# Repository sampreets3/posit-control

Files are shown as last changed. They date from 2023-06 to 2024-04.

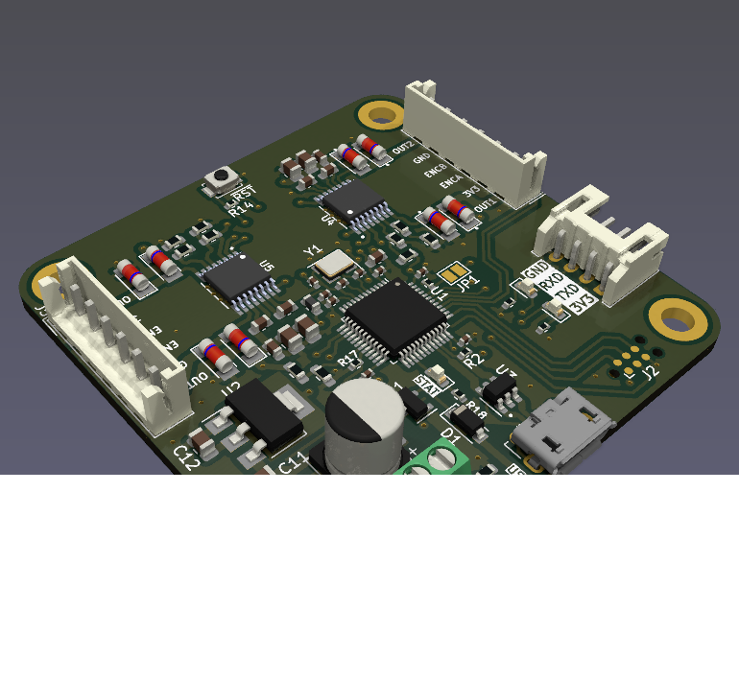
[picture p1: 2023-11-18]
images/four-layer-board.png

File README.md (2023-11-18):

# posit-control

Posit is an STM32-based DC motor controller designed to provide an efficient and reliable solution for controlling DC motors in various applications. This README file provides an overview of the Posit motor controller, its features, and instructions on getting started and using it in your projects.

---

## Features

- __STM32F1 Microcontroller:__ Posit is built around the STM32F103 microcontroller, known for its reliability and high-performance capabilities.

__USB Control:__ Posit acts as a USB Virtual COM Port, for sending over commands via usb->serial interfaces.

__UART Communication:__ UART interface for communication with external devices or microcontrollers.

---

## Usage

The Posit STM32 DC Motor Controller is highly customizable to fit a wide range of applications. You can control the motor speed and direction using PWM signals, monitor current feedback, and interface with external sensors for more advanced control.

Here is a basic example of controlling a motor using Posit:

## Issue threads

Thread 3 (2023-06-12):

Create Base Schematic

sampreets3, 2023-06-12:
Base Schematic Capture by defining requirements:

- [x] DRV8874
- [x] Microcontroller to interface with the driver
- [x] Power circuitry
- [x] USB data communication
- [ ] Optional: SPI LED bar control

sampreets3, 2023-06-25:
Added in commit cffd102.

Closed 2023-10-05.

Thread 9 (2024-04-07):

Add a debug LED on the board

aniketSaha1997, 2024-04-07:
Currently there are status LEDs but an additional LED would be good to have which can be helpful during debugging. For example - In case of the motor PWM apis, the LED could have been an added benefit in order to test whether the PWMs are set properly or not.

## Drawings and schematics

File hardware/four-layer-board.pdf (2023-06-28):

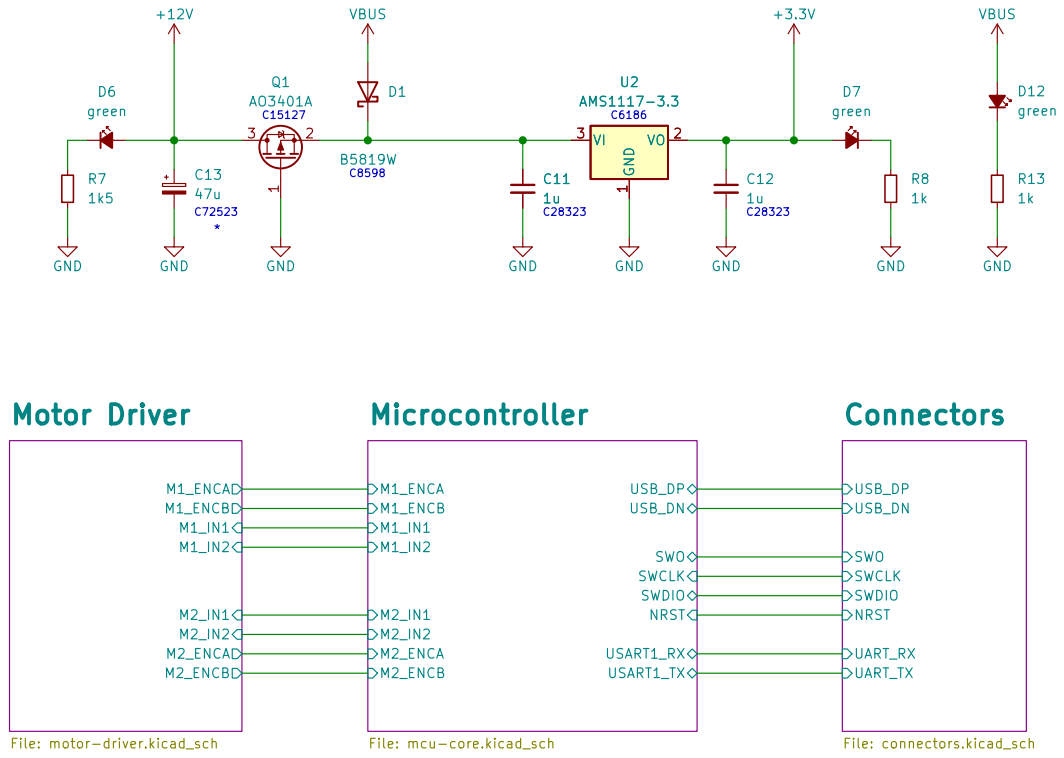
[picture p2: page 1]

Id: 1/4 Title: Posit: A STM32 based DC motor controller File: four-layer-board.kicad_sch Sheet: / Sampreet SARKAR

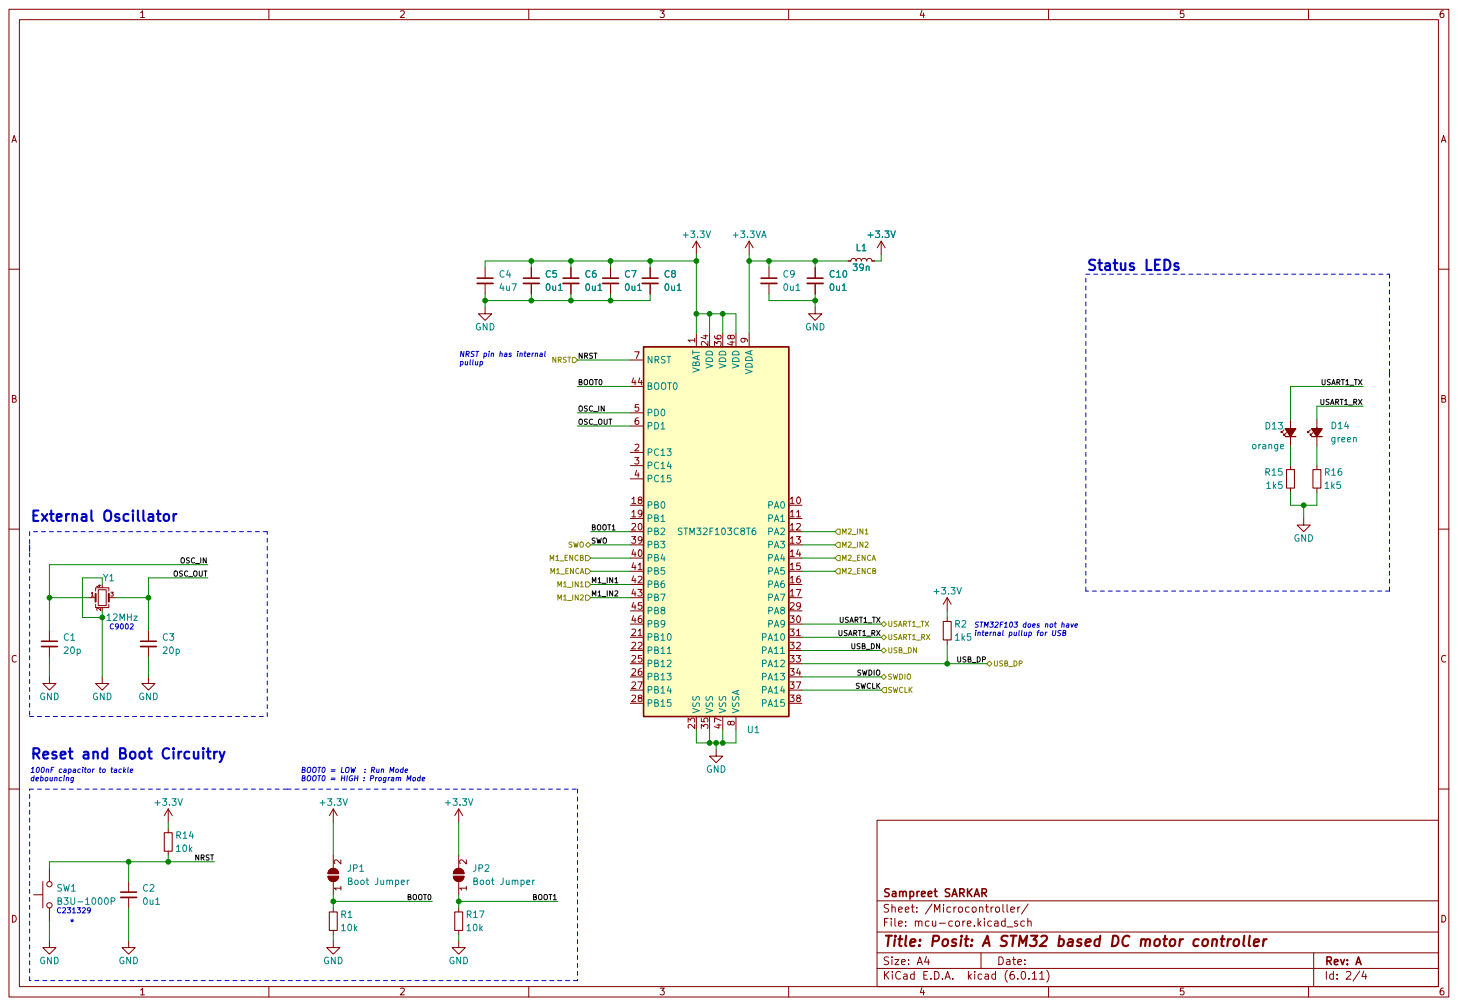
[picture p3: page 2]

debouncing Reset and Boot Circuitry

Id: 2/4 Title: Posit: A STM32 based DC motor controller File: mcu-core.kicad_sch Sheet: /Microcontroller/ Sampreet SARKAR

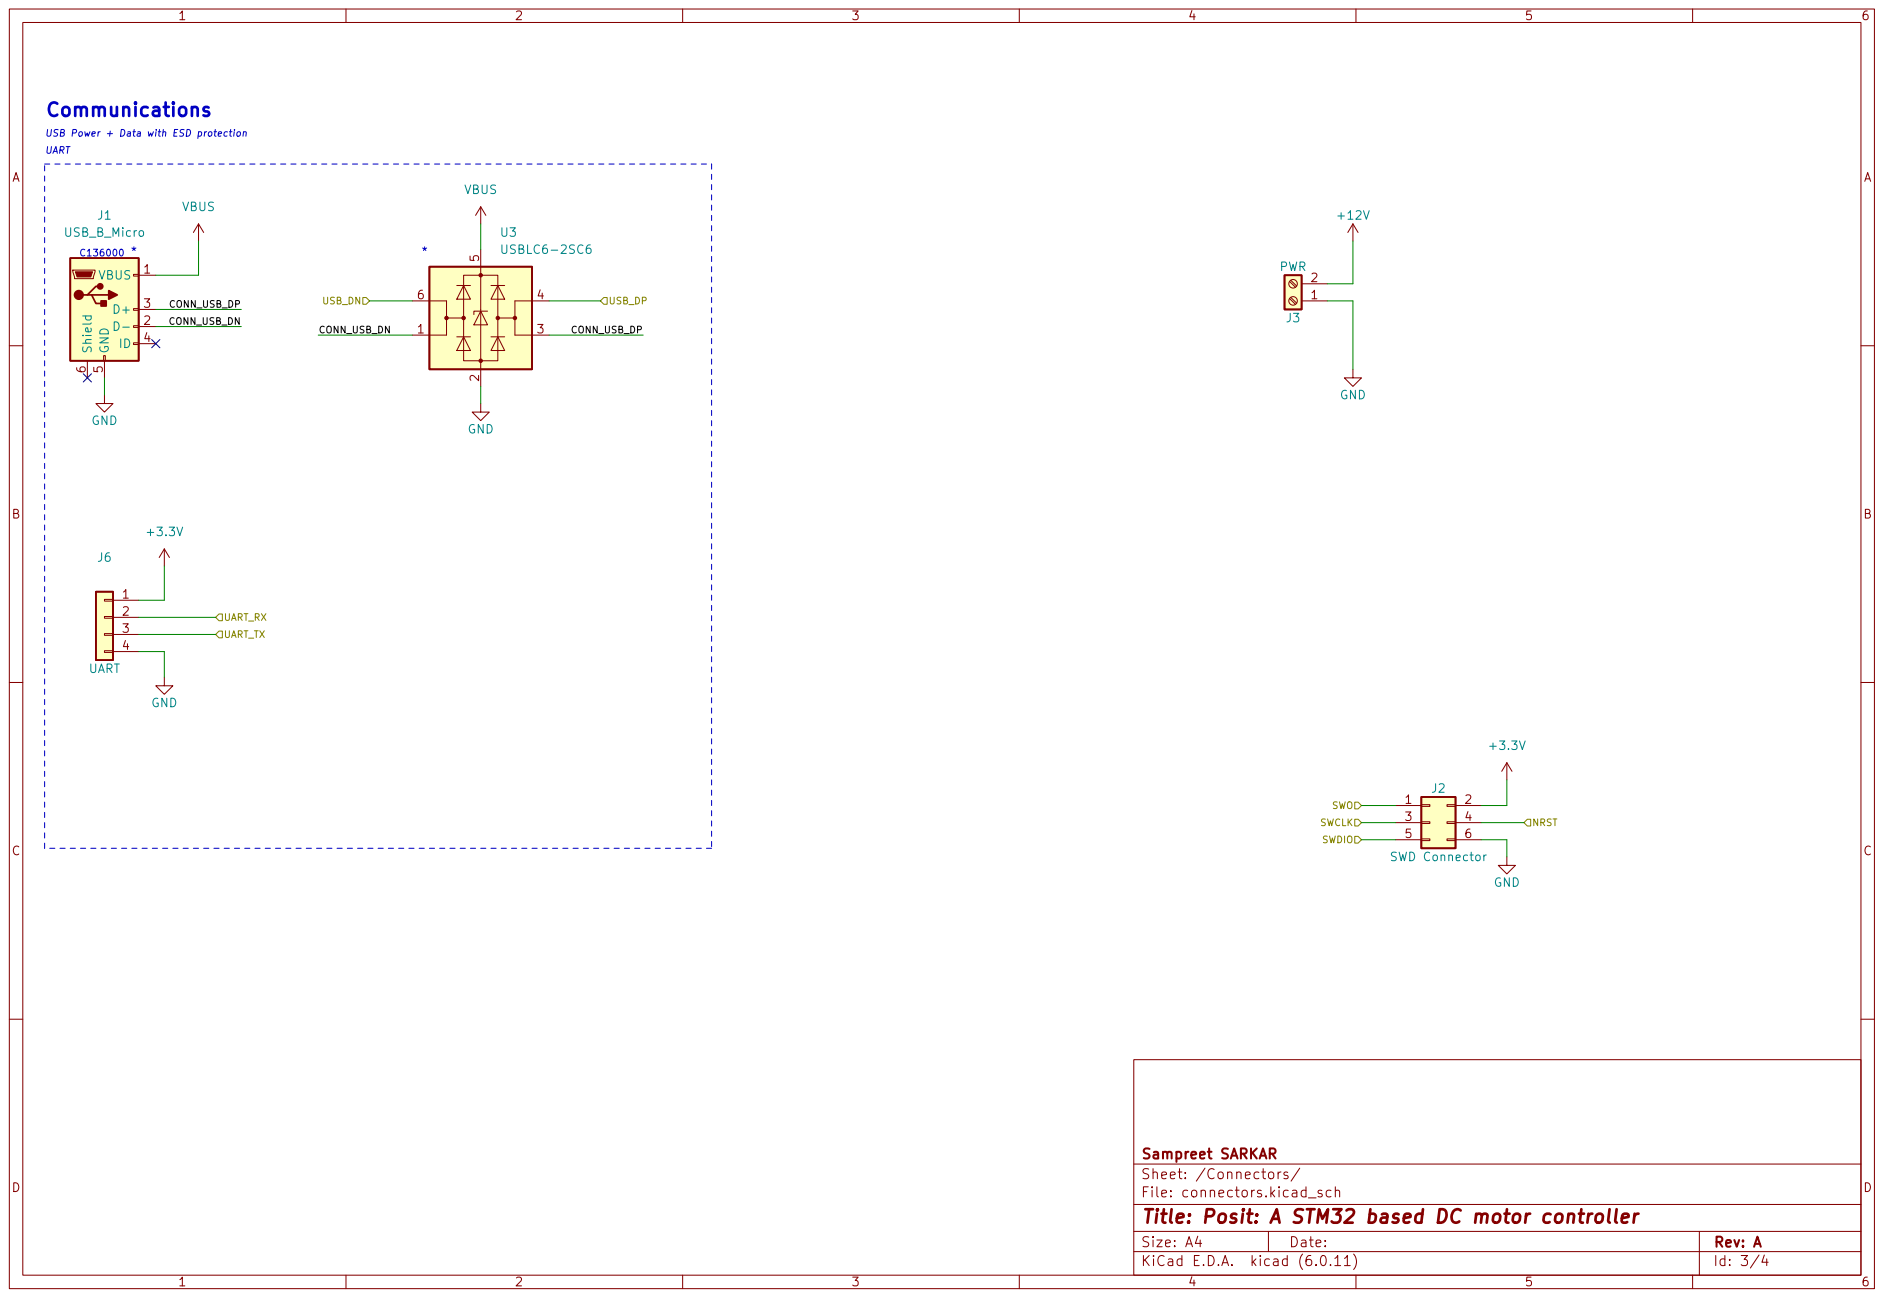
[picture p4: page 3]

* USB Power + Data with ESD protection Communications
J1 USB_B_Micro +3.3V

Id: 3/4 Title: Posit: A STM32 based DC motor controller File: connectors.kicad_sch Sheet: /Connectors/ Sampreet SARKAR

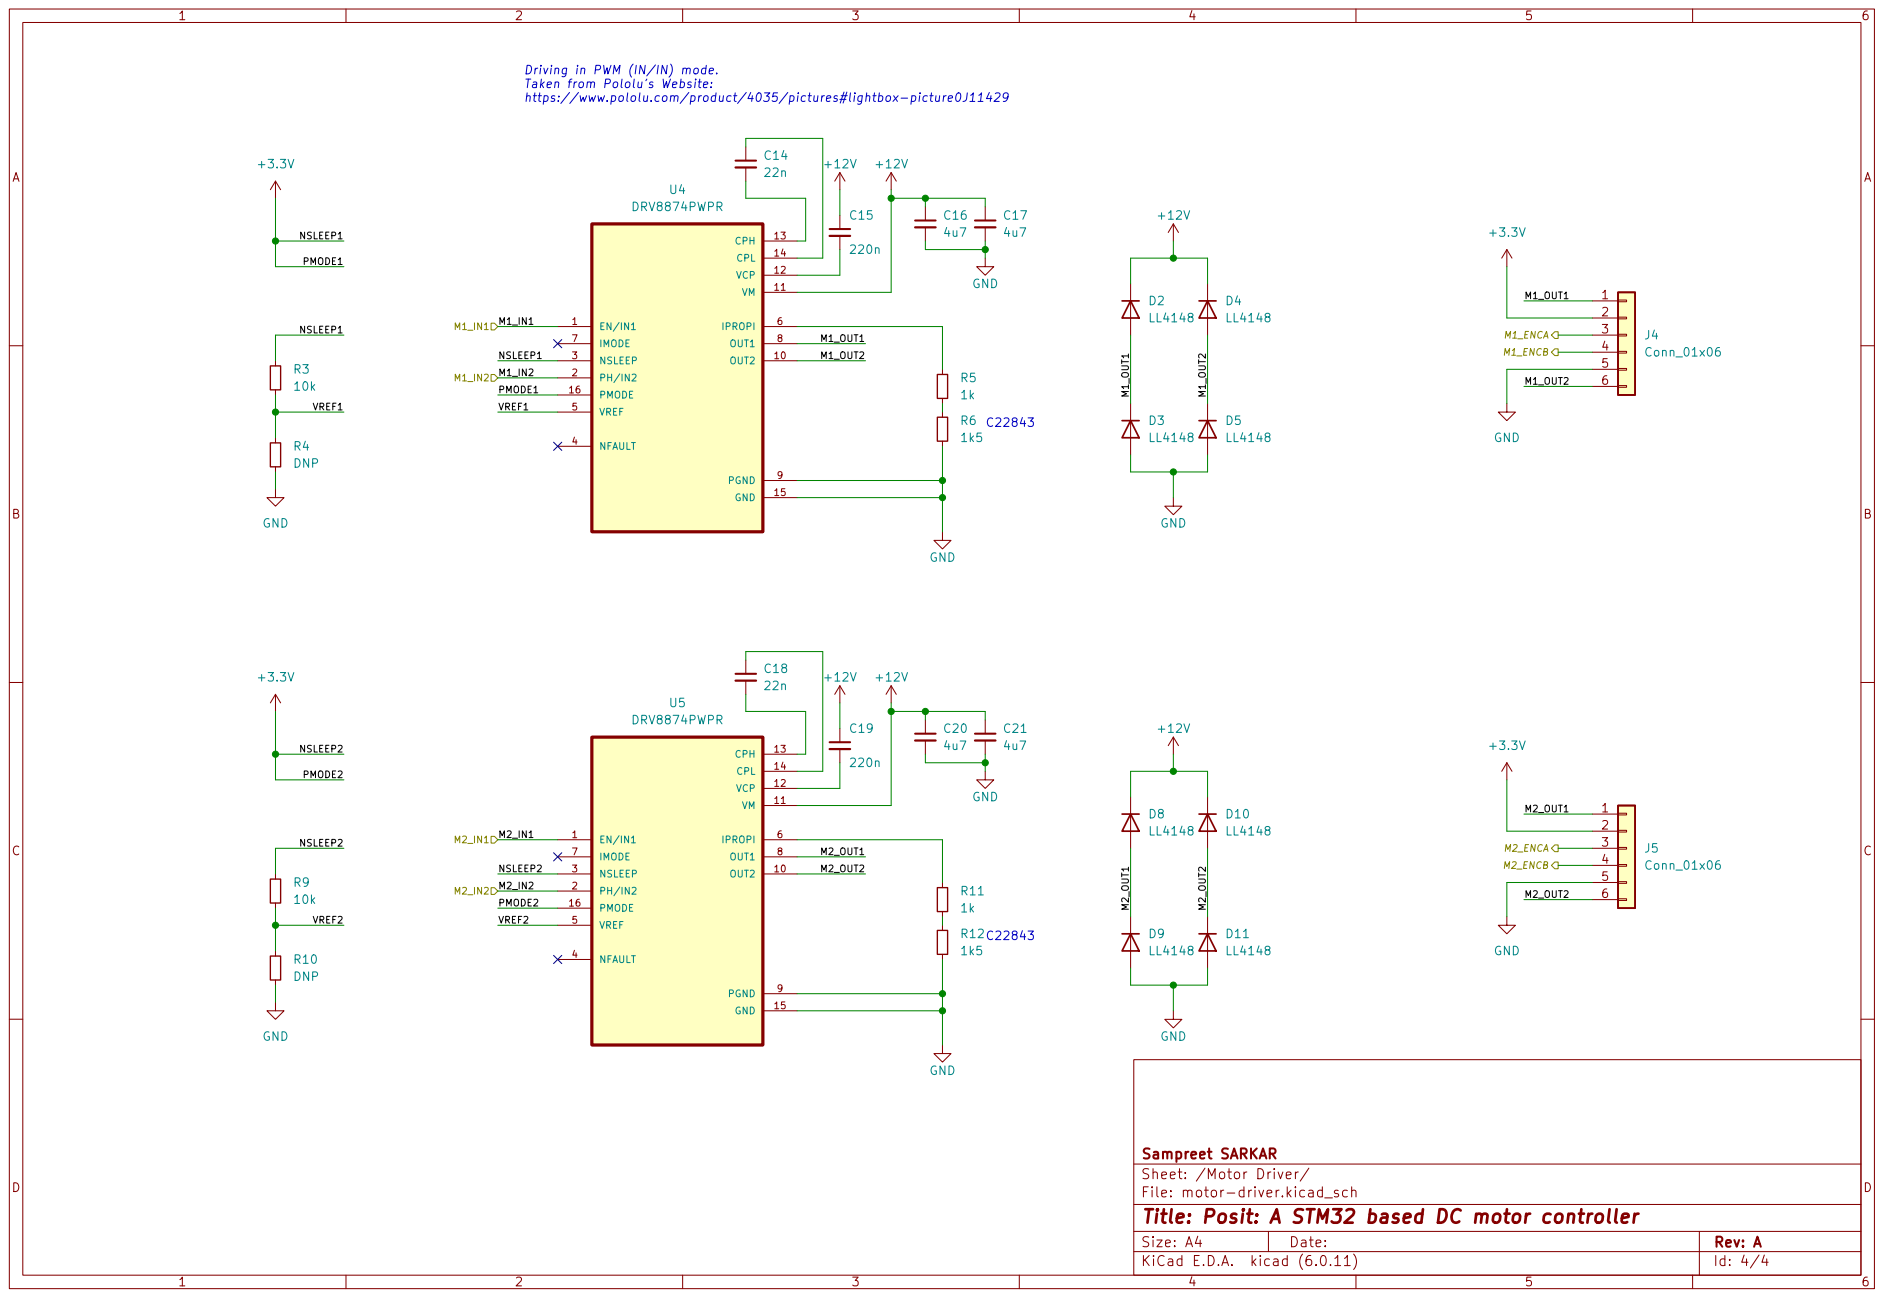
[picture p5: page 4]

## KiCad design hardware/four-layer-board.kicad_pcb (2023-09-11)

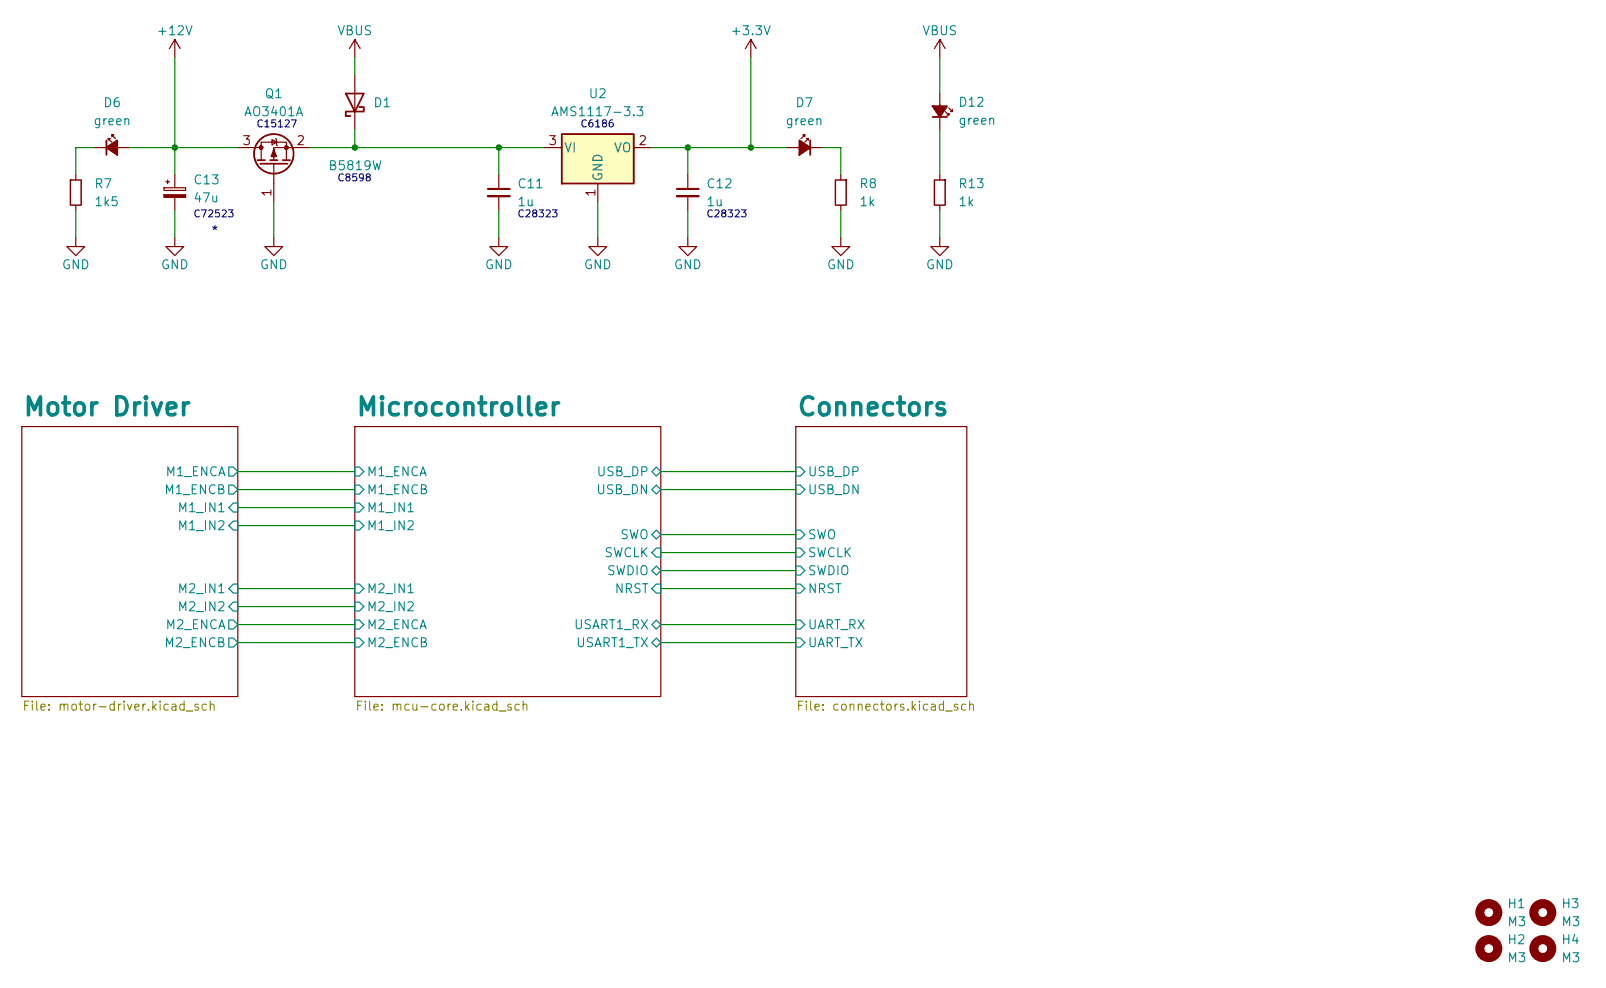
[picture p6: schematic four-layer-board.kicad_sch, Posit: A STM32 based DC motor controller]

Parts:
C11, C12: 1u; C_0805_2012Metric
C13: 47u; CP_Elec_6.3x7.7
D1: B5819W; D_SOD-123
D6, D7, D12: green; LED_0603_1608Metric
H1, H2, H3, H4: M3; MountingHole_3.2mm_M3_DIN965_Pad
Q1: AO3401A; SOT-23
R7: 1k5; R_0603_1608Metric
R8, R13: 1k; R_0603_1608Metric
U2: AMS1117-3.3; SOT-223-3_TabPin2

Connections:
+3.3V: C12.1, D7.2 (A), U2.2 (VO); also elsewhere on the board
+12V: C13.1, D6.2 (A), Q1.3 (D); also elsewhere on the board
GND: C11.2, C12.2, C13.2, Q1.1 (G), R7.2, R8.2, R13.2, U2.1 (GND); also elsewhere on the board
unnamed: C11.1, D1.1 (K), Q1.2 (S), U2.3 (VI)
unnamed: D6.1 (K), R7.1
unnamed: D7.1 (K), R8.1
unnamed: D12.1 (K), R13.1
VBUS: D1.2 (A), D12.2 (A); also elsewhere on the board

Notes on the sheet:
C28323
C6186
C15127
C8598
C72523

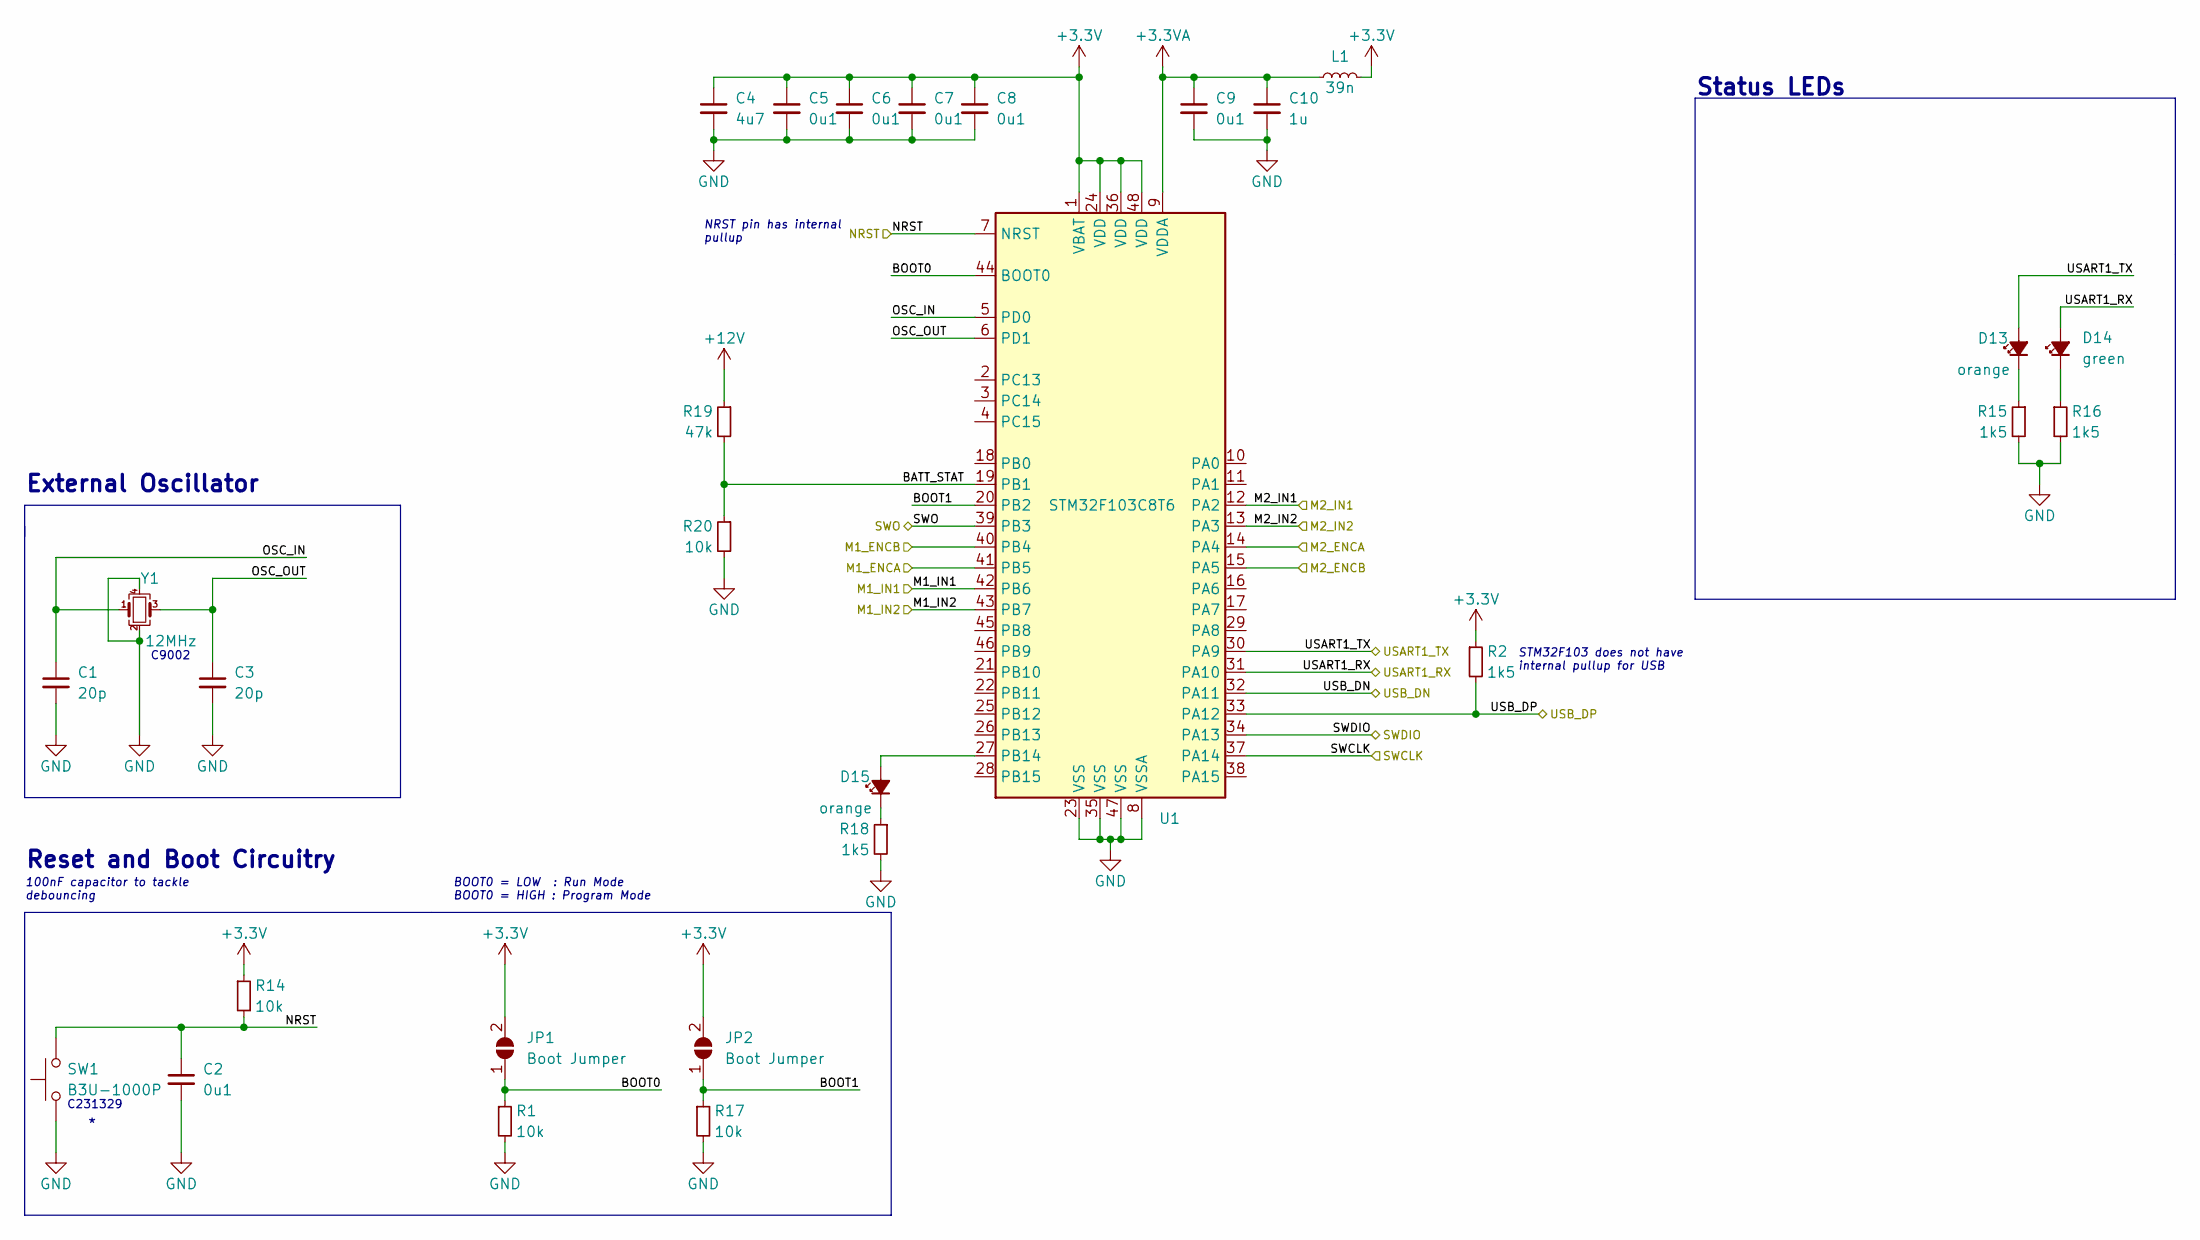
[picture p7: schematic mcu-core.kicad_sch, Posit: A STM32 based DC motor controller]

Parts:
C1, C3: 20p; C_0402_1005Metric
C2, C5, C6, C7, C8, C9: 0u1; C_0402_1005Metric
C4: 4u7; C_0603_1608Metric
C10: 1u; C_0402_1005Metric
D13, D15: orange; LED_0603_1608Metric
D14: green; LED_0603_1608Metric
JP1, JP2: Boot Jumper; SolderJumper-2_P1.3mm_Open_Pad1.0x1.5mm
L1: 39n; L_0603_1608Metric
R1, R14, R17: 10k; R_0402_1005Metric
R2, R15, R16, R18: 1k5; R_0402_1005Metric
R19: 47k; R_0603_1608Metric_Pad0.98x0.95mm_HandSolder
R20: 10k; R_0603_1608Metric_Pad0.98x0.95mm_HandSolder
SW1: B3U-1000P; SW_SPST_B3U-1000P
U1: STM32F103C8T6; LQFP-48_7x7mm_P0.5mm
Y1: 12MHz; Crystal_SMD_3225-4Pin_3.2x2.5mm

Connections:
+3.3V: C4.1, C5.1, C6.1, C7.1, C8.1, JP1.2 (B), JP2.2 (B), L1.2, R2.1, R14.1, U1.1 (VBAT), U1.24 (VDD), U1.36 (VDD), U1.48 (VDD); also elsewhere on the board
+3.3VA: C9.1, C10.1, L1.1, U1.9 (VDDA)
+12V: R19.1; also elsewhere on the board
/Microcontroller/BATT_STAT: R19.2, R20.1, U1.19 (PB1)
/Microcontroller/BOOT0: JP1.1 (A), R1.1, U1.44 (BOOT0)
/Microcontroller/BOOT1: JP2.1 (A), R17.1, U1.20 (PB2)
/Microcontroller/M1_ENCA: U1.41 (PB5); also elsewhere on the board
/Microcontroller/M1_ENCB: U1.40 (PB4); also elsewhere on the board
/Microcontroller/M1_IN1: U1.42 (PB6); also elsewhere on the board
/Microcontroller/M1_IN2: U1.43 (PB7); also elsewhere on the board
/Microcontroller/M2_ENCA: U1.14 (PA4); also elsewhere on the board
/Microcontroller/M2_ENCB: U1.15 (PA5); also elsewhere on the board
/Microcontroller/M2_IN1: U1.12 (PA2); also elsewhere on the board
/Microcontroller/M2_IN2: U1.13 (PA3); also elsewhere on the board
/Microcontroller/NRST: C2.1, R14.2, SW1.2, U1.7 (NRST); also elsewhere on the board
/Microcontroller/OSC_IN: C1.1, U1.5 (PD0), Y1.1
/Microcontroller/OSC_OUT: C3.1, U1.6 (PD1), Y1.3
/Microcontroller/SWCLK: U1.37 (PA14); also elsewhere on the board
/Microcontroller/SWDIO: U1.34 (PA13); also elsewhere on the board
/Microcontroller/SWO: U1.39 (PB3); also elsewhere on the board
/Microcontroller/USART1_RX: D14.2 (A), U1.31 (PA10); also elsewhere on the board
/Microcontroller/USART1_TX: D13.2 (A), U1.30 (PA9); also elsewhere on the board
/Microcontroller/USB_DN: U1.32 (PA11); also elsewhere on the board
/Microcontroller/USB_DP: R2.2, U1.33 (PA12); also elsewhere on the board
GND: C1.2, C2.2, C3.2, C4.2, C5.2, C6.2, C7.2, C8.2, C9.2, C10.2, R1.2, R15.2, R16.2, R17.2, R18.2, R20.2, SW1.1, U1.8 (VSSA), U1.23 (VSS), U1.35 (VSS), U1.47 (VSS), Y1.2, Y1.4; also elsewhere on the board
unnamed: D13.1 (K), R15.1
unnamed: D14.1 (K), R16.1
unnamed: D15.2 (A), U1.27 (PB14)
unnamed: D15.1 (K), R18.1

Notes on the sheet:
External Oscillator
STM32F103 does not have internal pullup for USB
100nF capacitor to tackle debouncing
Status LEDs
NRST pin has internal pullup
Reset and Boot Circuitry
C9002
C231329
BOOT0 = LOW : Run Mode BOOT0 = HIGH : Program Mode

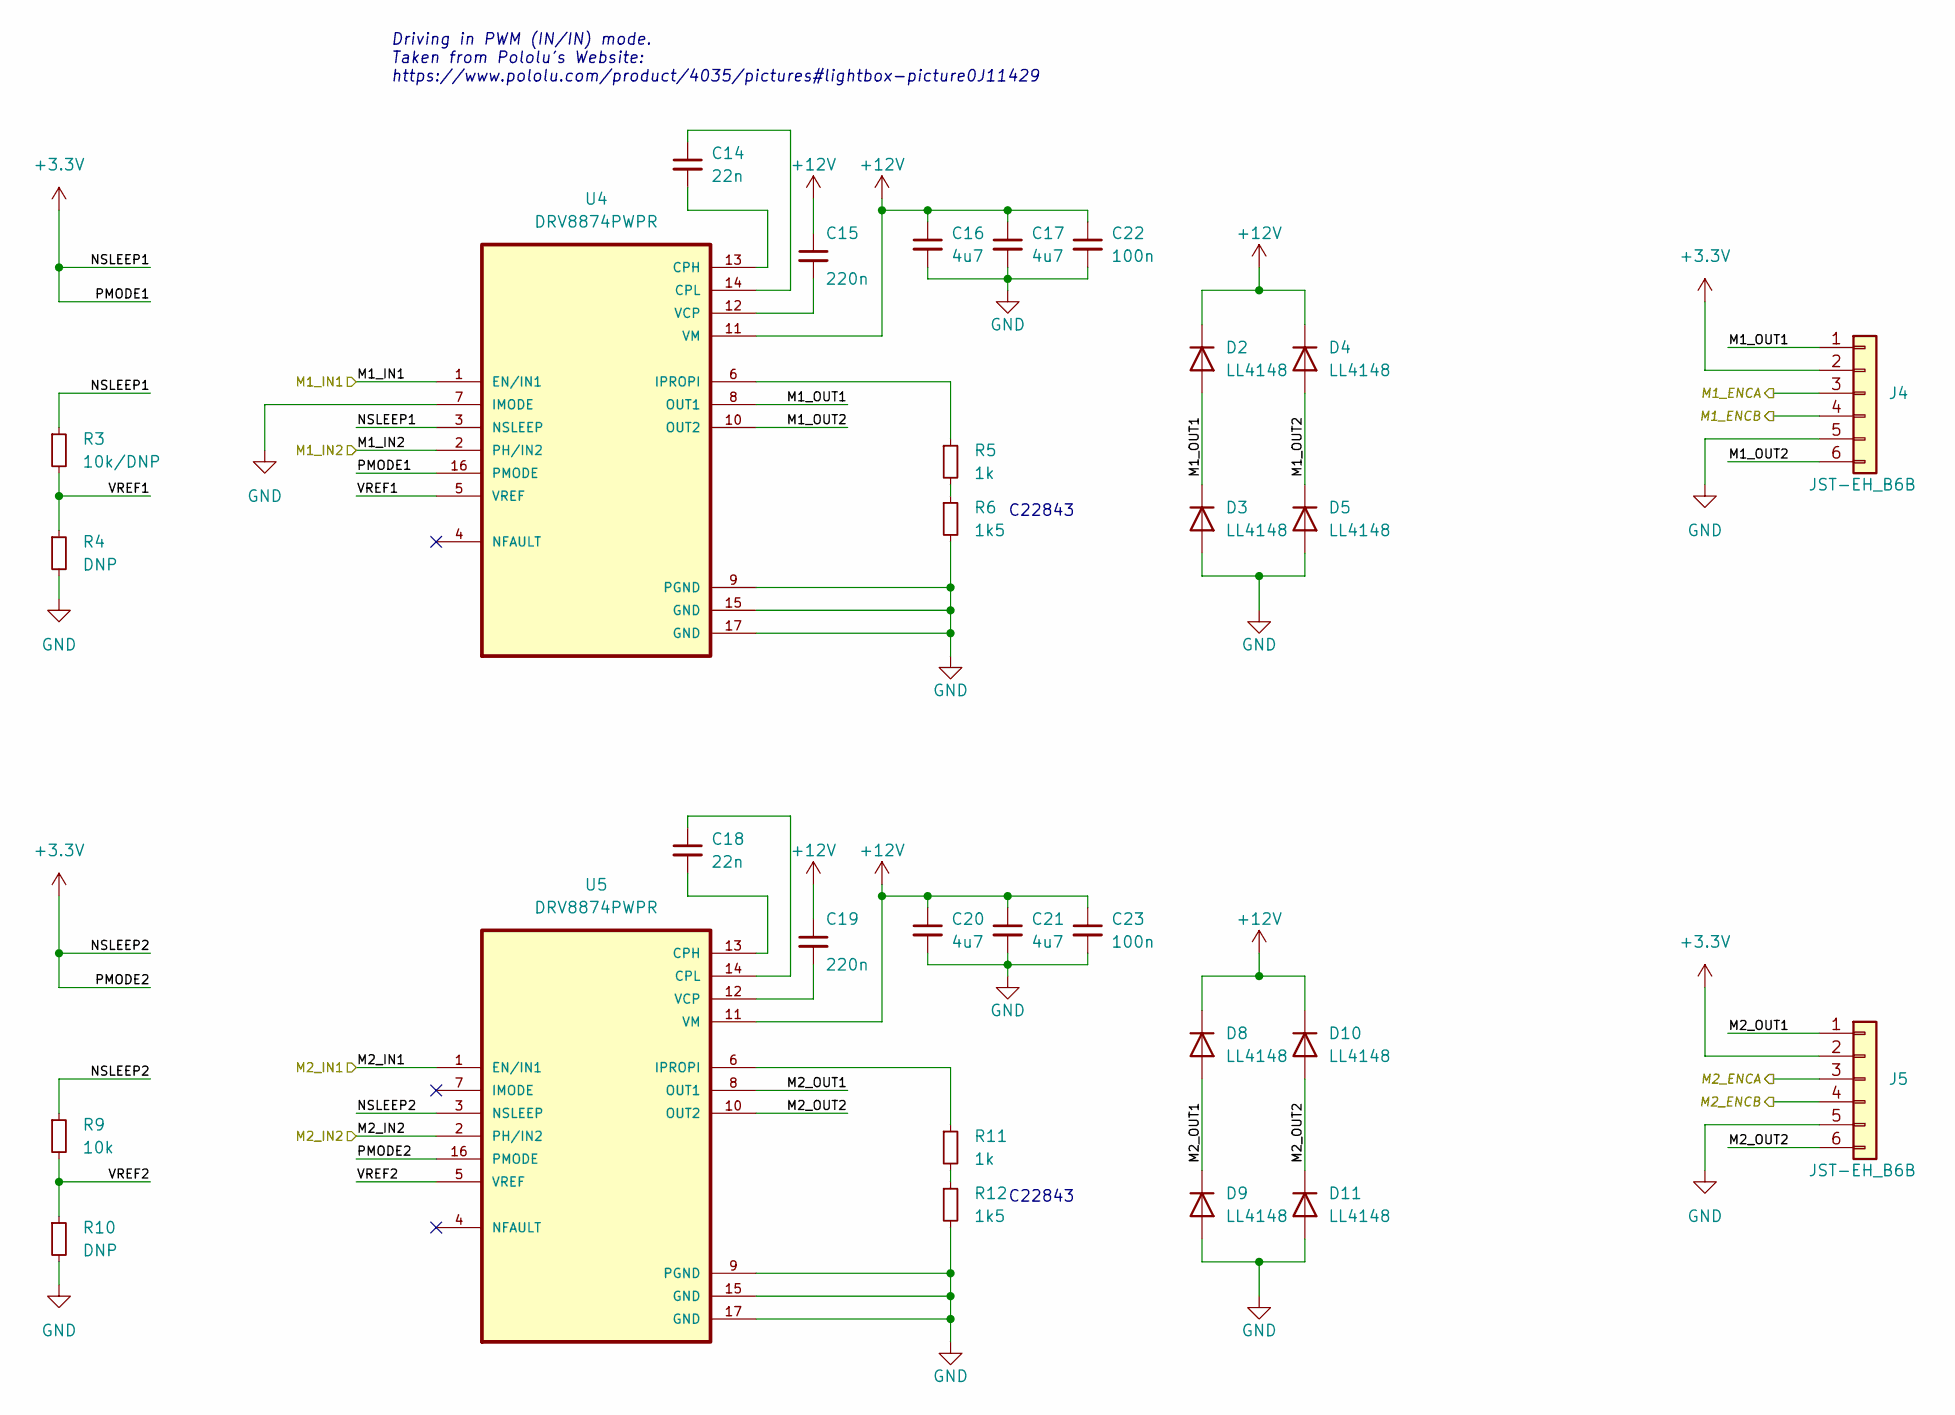
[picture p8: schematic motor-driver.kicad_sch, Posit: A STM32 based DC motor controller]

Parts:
C14, C18: 22n; C_0603_1608Metric
C15, C19: 220n; C_0603_1608Metric
C16, C17, C20, C21: 4u7; C_0805_2012Metric
C22, C23: 100n; C_0603_1608Metric
D2, D3, D4, D5, D8, D9, D10, D11: LL4148; D_MiniMELF
J4, J5: JST-EH_B6B; JST_EH_B6B-EH-A_1x06_P2.50mm_Vertical
R3: 10k/DNP; R_0603_1608Metric
R4, R10: DNP; R_0603_1608Metric
R5, R11: 1k; R_0603_1608Metric
R6, R12: 1k5; R_0603_1608Metric
R9: 10k; R_0603_1608Metric
U4, U5: DRV8874PWPR; SOP65P640X120-17N

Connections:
+3.3V: J4.2, J5.2, R3.1, R9.1, U4.3 (NSLEEP), U4.16 (PMODE), U5.3 (NSLEEP), U5.16 (PMODE); also elsewhere on the board
+12V: C15.1, C16.1, C17.1, C19.1, C20.1, C21.1, C22.1, C23.1, D2.1 (K), D4.1 (K), D8.1 (K), D10.1 (K), U4.11 (VM), U5.11 (VM); also elsewhere on the board
/Microcontroller/M1_ENCA: J4.3; also elsewhere on the board
/Microcontroller/M1_ENCB: J4.4; also elsewhere on the board
/Microcontroller/M1_IN1: U4.1 (EN/IN1); also elsewhere on the board
/Microcontroller/M1_IN2: U4.2 (PH/IN2); also elsewhere on the board
/Microcontroller/M2_ENCA: J5.3; also elsewhere on the board
/Microcontroller/M2_ENCB: J5.4; also elsewhere on the board
/Microcontroller/M2_IN1: U5.1 (EN/IN1); also elsewhere on the board
/Microcontroller/M2_IN2: U5.2 (PH/IN2); also elsewhere on the board
/Motor Driver/M1_OUT1: D2.2 (A), D3.1 (K), J4.1, U4.8 (OUT1)
/Motor Driver/M1_OUT2: D4.2 (A), D5.1 (K), J4.6, U4.10 (OUT2)
/Motor Driver/M2_OUT1: D8.2 (A), D9.1 (K), J5.1, U5.8 (OUT1)
/Motor Driver/M2_OUT2: D10.2 (A), D11.1 (K), J5.6, U5.10 (OUT2)
/Motor Driver/VREF1: R3.2, R4.1, U4.5 (VREF)
/Motor Driver/VREF2: R9.2, R10.1, U5.5 (VREF)
GND: C16.2, C17.2, C20.2, C21.2, C22.2, C23.2, D3.2 (A), D5.2 (A), D9.2 (A), D11.2 (A), J4.5, J5.5, R4.2, R6.2, R10.2, R12.2, U4.7 (IMODE), U4.9 (PGND), U4.15 (GND), U4.17 (GND), U5.9 (PGND), U5.15 (GND), U5.17 (GND); also elsewhere on the board
unnamed: R5.2, R6.1
unnamed: R11.2, R12.1
unnamed: C14.2, U4.13 (CPH)
unnamed: C14.1, U4.14 (CPL)
unnamed: R5.1, U4.6 (IPROPI)
unnamed: C15.2, U4.12 (VCP)
unnamed: C18.2, U5.13 (CPH)
unnamed: C18.1, U5.14 (CPL)
unnamed: R11.1, U5.6 (IPROPI)
unnamed: C19.2, U5.12 (VCP)

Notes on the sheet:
C22843
Driving in PWM (IN/IN) mode. Taken from Pololu's Website: https://www.pololu.com/product/4035/pictures#lightbox-picture0J11429

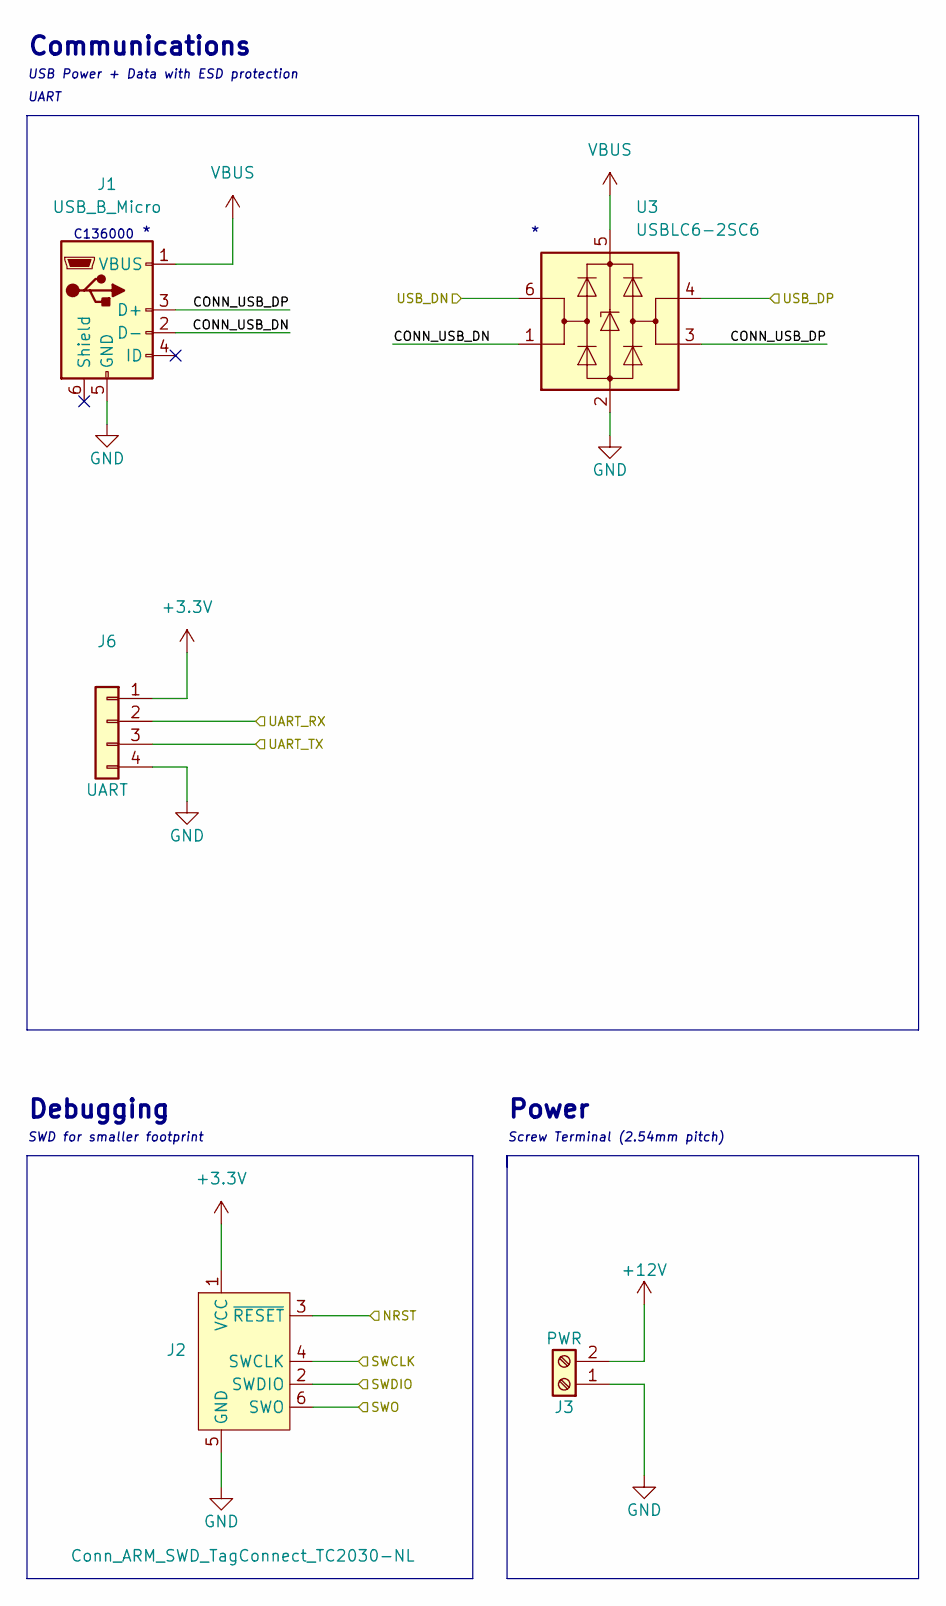
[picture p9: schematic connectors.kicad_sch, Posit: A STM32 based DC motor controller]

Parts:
J1: USB_B_Micro; USB_Micro-B_Molex-105017-0001
J2: Conn_ARM_SWD_TagConnect_TC2030-NL; Tag-Connect_TC2030-IDC-NL_2x03_P1.27mm_Vertical
J3: PWR; TerminalBlock_Phoenix_MPT-0,5-2-2.54_1x02_P2.54mm_Horizontal
J6: UART; JST_PH_S4B-PH-K_1x04_P2.00mm_Horizontal
U3: USBLC6-2SC6; SOT-23-6

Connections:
+3.3V: J2.1 (VCC), J6.1; also elsewhere on the board
+12V: J3.2; also elsewhere on the board
/Connectors/CONN_USB_DN: J1.2 (D-), U3.1 (I/O1)
/Connectors/CONN_USB_DP: J1.3 (D+), U3.3 (I/O2)
/Microcontroller/NRST: J2.3 (~RESET); also elsewhere on the board
/Microcontroller/SWCLK: J2.4 (SWCLK); also elsewhere on the board
/Microcontroller/SWDIO: J2.2 (SWDIO); also elsewhere on the board
/Microcontroller/SWO: J2.6 (SWO); also elsewhere on the board
/Microcontroller/USART1_RX: J6.2; also elsewhere on the board
/Microcontroller/USART1_TX: J6.3; also elsewhere on the board
/Microcontroller/USB_DN: U3.6 (I/O1); also elsewhere on the board
/Microcontroller/USB_DP: U3.4 (I/O2); also elsewhere on the board
GND: J1.5 (GND), J2.5 (GND), J3.1, J6.4, U3.2 (GND); also elsewhere on the board
VBUS: J1.1 (VBUS), U3.5 (VBUS); also elsewhere on the board

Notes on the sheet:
Debugging
UART
C136000
Power
SWD for smaller footprint
USB Power + Data with ESD protection
Communications
Screw Terminal (2.54mm pitch)

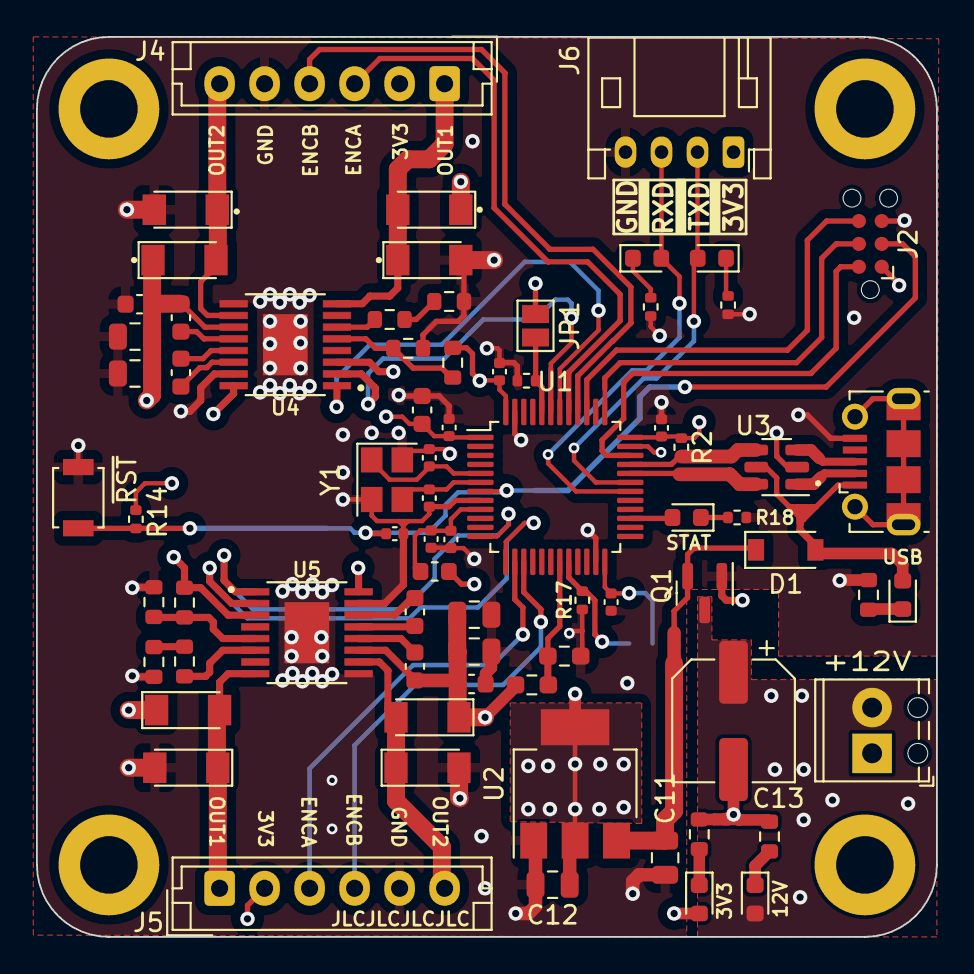
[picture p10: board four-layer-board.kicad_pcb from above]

Board: 4 copper layers, 50.0 x 50.0 mm, 79 parts (1 on the bottom side), 52 nets.

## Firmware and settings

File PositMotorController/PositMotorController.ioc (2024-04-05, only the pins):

Mcu.UserName=STM32F103C8Tx
PA13.Signal=SYS_JTMS-SWDIO
PA14.Signal=SYS_JTCK-SWCLK
PA2.GPIO_Label=M2_IN1
PA2.Signal=S_TIM2_CH3
PA3.GPIO_Label=M2_IN2
PA3.Signal=S_TIM2_CH4
PB3.Signal=SYS_JTDO-TRACESWO
PB6.GPIO_Label=M1_IN1
PB6.Signal=S_TIM4_CH1
PB7.GPIO_Label=M1_IN2
PB7.Signal=S_TIM4_CH2
PD0-OSC_IN.Signal=RCC_OSC_IN
PD1-OSC_OUT.Signal=RCC_OSC_OUT

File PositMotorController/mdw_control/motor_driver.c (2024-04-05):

/**
 * @file
 *
 * @brief		Middleware layer for controlling motor rotation.
 *
 */

/******************************************************************************
 * Include Header Files
 ******************************************************************************/
#include "motor_driver.h"
#include "drv8874.h"

/******************************************************************************
 * Extern Function Definitions
 ******************************************************************************/
extern void MotorDriverInit(void)
{
	DrvLowInitController();
}


extern void MotorDriverStartMotor(DrvLowMotorSelectorEn selector_en, DrvLowMotorDirectionEn dir_en, uint16_t speed_u16)
{
	DrvLowStartMotor(selector_en, dir_en, speed_u16);
}


extern void MotorDriverMoveForward(uint16_t speed_u16)
{
	DrvLowMotorMoveForward(DRV_LOW_RIGHT_MOTOR, speed_u16);
	DrvLowMotorMoveForward(DRV_LOW_LEFT_MOTOR, speed_u16);
}


extern void MotorDriverMoveBackward(uint16_t speed_u16)
{
	DrvLowMotorMoveReverse(DRV_LOW_RIGHT_MOTOR, speed_u16);
	DrvLowMotorMoveReverse(DRV_LOW_LEFT_MOTOR, speed_u16);
}


extern void MotorDriverStopMotor(DrvLowMotorSelectorEn selector_en)
{
	DrvLowStopMotor(selector_en);
}

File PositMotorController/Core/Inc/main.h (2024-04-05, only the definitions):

#define M2_IN1_Pin GPIO_PIN_2
#define M2_IN1_GPIO_Port GPIOA
#define M2_IN2_Pin GPIO_PIN_3
#define M2_IN2_GPIO_Port GPIOA
#define M1_IN1_Pin GPIO_PIN_6
#define M1_IN1_GPIO_Port GPIOB
#define M1_IN2_Pin GPIO_PIN_7
#define M1_IN2_GPIO_Port GPIOB

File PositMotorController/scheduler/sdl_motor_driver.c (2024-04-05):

/**
 * @file
 *
 * @brief		Scheduler to test motor control driver.
 *
 */

/******************************************************************************
 * Include Header Files
 ******************************************************************************/
#include "stdbool.h"
#include "motor_driver.h"
#include "stm32f1xx_hal.h"

/******************************************************************************
 * Module Global Variables
 ******************************************************************************/
static uint16_t speed_gu16 = 0u;
static bool flag_b = false;

/******************************************************************************
 * Extern Function Definitions
 ******************************************************************************/

extern void SdlMotorDriverInit(void)
{
	MotorDriverInit();
}

extern void SdlMotorDriverRun(void)
{
	if(flag_b == false)
	{
		MotorDriverStartMotor(DRV_LOW_RIGHT_MOTOR, DRV_LOW_DIR_FW, 10u);
		MotorDriverStartMotor(DRV_LOW_RIGHT_MOTOR, DRV_LOW_DIR_REV, 10u);
		MotorDriverStartMotor(DRV_LOW_LEFT_MOTOR, DRV_LOW_DIR_FW, 10u);
		MotorDriverStartMotor(DRV_LOW_LEFT_MOTOR, DRV_LOW_DIR_REV, 10u);

		flag_b = true;
	}

	while(speed_gu16 != 80u)
	{
		MotorDriverMoveForward(speed_gu16);
		HAL_Delay(1000uL);
		MotorDriverMoveBackward(speed_gu16);

		speed_gu16 += 10u;
	}

	speed_gu16 = 0u;
}

/******************************************************************************
 * Callback Function Definitions
 ******************************************************************************/

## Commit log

2023-06-12 Cleanup commit
    [bom.csv, connectors.kicad_sch, designators.csv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]
2023-06-25 Switched to a four layer design
    [5mm-spacers.SLDPRT, Assem3.SLDASM, base-plate.SLDPRT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]
2023-06-25 Modified gitignore
    [four-layer-board.kicad_sch, mcu-core.kicad_sch]
2023-06-25 Added connections for motor 2
    [four-layer-board.kicad_pcb, four-layer-board.kicad_sch, mcu-core.kicad_sch]
2023-06-25 Moved hardware to separate directory
    [connectors.kicad_sch, four-layer-board.kicad_pcb, four-layer-board.kicad_sch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]
2023-06-25 Added pin assignments in firmware
    [connectors.kicad_sch, four-layer-board.kicad_sch, mcu-core.kicad_sch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]
2023-06-27 Added LEDs and UART
    [connectors.kicad_sch, four-layer-board.kicad_pcb, four-layer-board.kicad_sch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]
2023-06-28 Added BOOT1 jumper
    [four-layer-board.kicad_pcb, four-layer-board.kicad_sch, mcu-core.kicad_sch]
2023-06-29 Added status LED and silkscreen
    [four-layer-board.kicad_pcb, four-layer-board.kicad_sch, mcu-core.kicad_sch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]
2023-07-07 Minor changes, added 100n cap
    [four-layer-board.kicad_pcb, four-layer-board.kicad_sch, mcu-core.kicad_sch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]
2023-08-09 Updated hardware design, added TagConnect Probe and Battery Voltage Measurement
    [connectors.kicad_sch, four-layer-board.kicad_pcb, four-layer-board.kicad_sch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]
2023-09-02 Updated design, ready to generate production files
    [connectors.kicad_sch, four-layer-board.kicad_pcb, four-layer-board.kicad_sch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]
2023-09-11 Cleaned up debug firmware
    [four-layer-board.kicad_pcb, motor-driver.kicad_sch]
2023-09-11 Fixed missing timer for toggle
2023-12-13 Removed STM32 Project
2024-04-04 Added middleware and lower level driver for motor controller
2024-04-04 Document header added along with missed file for scheduler
    [sdl_motor_driver.c]
2024-04-04 Replaced not working project with a working
    [PositMotorController.ioc, main.h, motor_driver.c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]
2024-04-04 Minor fixes and api added in header file
    [sdl_motor_driver.c]
2024-04-05 Addded back motor selector logic, open loop conditions incorporated.
2024-04-05 Renamed drv_low folder and refactored driver file names

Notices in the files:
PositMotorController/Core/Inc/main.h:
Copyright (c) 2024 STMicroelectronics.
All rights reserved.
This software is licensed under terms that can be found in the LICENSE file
